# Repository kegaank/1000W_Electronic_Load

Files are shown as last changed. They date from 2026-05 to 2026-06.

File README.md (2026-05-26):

# 1000W 可编程直流电子负载

> **项目代号**: EL-1000  |  **12维度闭环管理 v3.0**  |  **人机协作模式**

---

## 项目速览

| 项 | 值 |
|---|---|
| 产品定位 | ITECH级精度 + 美尔诺级定价 + 现代化软件体验 |
| 目标零售价 | ¥3,999-5,999（约$550-830） |
| 核心规格 | 1000W连续 / 0-150V / 0-60A / 0.1%精度 / Wi-Fi+BLE+USB |
| 团队 | 创始人（执行合伙人）+ AI数字化研发团队 |
| 开发周期 | 24周（6个月）至首次发布 |

---

## 目录结构

```
1000W_Electronic_Load/
├── README.md                 ← 本文件
├── 01_市场调研/              ← 竞品分析、用户画像、市场报告
├── 02_产品定义/              ← PRD、SRD、ID Brief
├── 03_系统设计/              ← 系统架构图、功率拓扑、热设计
├── 04_外观结构/              ← ID设计需求、3D模型、结构图纸
├── 05_硬件研发/              ← 原理图、PCB、BOM
├── 06_软件研发/              ← 固件、Web UI、App、云端
├── 07_测试验证/              ← 测试计划、校准流程、测试报告
├── 08_供应链/                ← 供应商列表、比价表、采购订单
├── 09_推广运营/              ← 博客、视频脚本、众筹文案
├── 10_销售渠道/              ← 电商文案、FAQ、产品说明书
├── 11_客户成功/              ← 用户手册、NPS问卷、反馈汇总
├── 12_项目管理/              ← 排期表、评审材料、风险追踪
├── _archive/                 ← 历史版本归档
├── _templates/               ← 文档模板
└── _meeting_notes/           ← 评审会议纪要
```

---

## 12维度 → 角色分工

| 角色 | 负责维度 | 成员 |
|---|---|---|
| A: 产品/市场 | 01, 02, 09, 10, 11 | 创始人 + AI辅助 |
| B: 系统/硬件 | 03, 04, 05, 07, 08 | 创始人 + AI辅助 |
| C: 软件 | 06 | AI主力 + 创始人测试 |
| D: 项目管理 | 12 | AI主力 + 创始人审核 |

---

## 阶段 & 里程碑

| 阶段 | 时间 | 关键节点 |
|---|---|---|
| 调研&定义 | W1-W6 | W6: SDR系统设计评审 |
| 设计&原型 | W7-W14 | W14: 原型机验收 |
| 验证&量产 | W15-W20 | W20: 发布就绪评审 |
| 发布&运营 | W21+ | 众筹/电商正式上线 |

---

## 协作流程

```
会话开始 → AI产出本周交付物 → 创始人执行物理任务 → 反馈结果 → 状态更新 → 下一周
```

---

## Git 仓库

> 初始化后填入仓库地址

---

*Created: 2026-05-26  |  Version: 1.0  |  密级: 内部*

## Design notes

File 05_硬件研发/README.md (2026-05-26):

# 05 硬件研发

## 子目录
```
05_硬件研发/
├── README.md
├── 原理图/
├── PCB/
├── BOM/
├── 调试日志/
└── 版本记录/
```

## 关键交付物

| 文档 | 状态 | 负责人 |
|---|---|---|
| 原理图（KiCad） | ⏳ 待开始 | AI |
| PCB Layout 指南 | ⏳ | AI |
| BOM 物料清单 V1.0 | ⏳ | AI |
| PCB Gerber 文件 | ⏳ | 用户 |
| 焊接 & 调试日志 | ⏳ | 用户 |
| 硬件版本迭代记录 | ⏳ | AI |

## 对应周次
W8-W14（V1.1持续迭代）

## 联动维度
- ← 03 系统设计
- ← 04 外观结构（PCB外形/限高）
- → 06 软件研发（联调）
- → 07 测试验证

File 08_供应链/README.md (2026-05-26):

# 08 供应链与生产制造

## 子目录
```
08_供应链/
├── README.md
├── PCB_供应商/
├── 元器件/
├── 结构件/
├── 组装/
├── 比价表/
└── 采购订单/
```

## 关键交付物

| 文档 | 状态 | 负责人 |
|---|---|---|
| 量产 BOM + 供应商比价表 | ⏳ | AI |
| 供应链跟踪表 | ⏳ | AI |
| 元器件采购订单 | ⏳ | 用户 |
| 结构件（模具/钣金）订单 | ⏳ | 用户 |
| 首批50台生产指导文档 | ⏳ | AI |

## 对应周次
W16-W20（持续管理）

## 联动维度
- ← 04 外观结构（模具需求）
- ← 05 硬件研发（BOM清单）
- ← 07 测试验证（验证通过后启动）
- → 10 销售渠道（量产成品）

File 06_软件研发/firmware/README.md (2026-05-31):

# EL-1000 Firmware — 1000W Programmable DC Electronic Load

## Overview

Dual-MCU architecture for a 1000W programmable DC electronic load.

| MCU | Role | Key Features |
|-----|---|---|
| **C2000 F28E12x** | Real-time control | PID @860Hz, protection @1ms, HRPWM @25kHz |
| **ESP32-S3** | Communication & UI | Wi-Fi 6 + BLE 5.0, WebSocket/REST API, 4.3" IPS LCD |

## Directory Layout

```
firmware/
├── README.md            ← This file
├── c2000/               ← C2000 F28E12x firmware (C/FreeRTOS)
│   ├── CMakeLists.txt
│   ├── main.c
│   ├── FreeRTOSConfig.h
│   ├── tasks/           ← FreeRTOS task implementations
│   ├── drivers/         ← Peripheral driver layer
│   └── control/         ← Control loop logic (PID, modes)
├── esp32/               ← ESP32-S3 firmware (ESP-IDF)
│   ├── CMakeLists.txt
│   ├── main/            ← Application code
│   └── components/      ← LVGL, protocol handlers
├── common/              ← Shared types & protocol definitions
└── docs/                ← Architecture documentation
```

## Build Instructions

### C2000
1. Open CCS Theia, import `firmware/` as a CCS project.
2. Select build target: `F28E12x`.
3. Build and flash via XDS110 debug probe.

### ESP32
1. Source ESP-IDF environment:
   ```
   . $HOME/esp/esp-idf/export.sh
   ```
2. Build:
   ```
   cd firmware/esp32
   idf.py build
   ```
3. Flash:
   ```
   idf.py -p /dev/ttyUSB0 flash monitor
   ```

## Inter-MCU Communication

UART (SCI-A on C2000 ↔ UART0 on ESP32) using a custom binary protocol defined in `common/protocol.h`.  
Baud rate: 921600. Packet format: start byte + length + command + payload + CRC.

## Real-Time Constraints

| Loop | Frequency | Deadline | MCU |
|---|---|---|-----|
| PID current control | 860 Hz | 1.16 ms | C2000 |
| Protection monitor | 1 kHz | 1.00 ms | C2000 |
| HRPWM update | 25 kHz | 40 µs | C2000 (ISR) |
| UART comms | 100 Hz | 10 ms | Both |
| Display refresh | 30 Hz | 33 ms | ESP32 |
| WebSocket push | 10 Hz | 100 ms | ESP32 |

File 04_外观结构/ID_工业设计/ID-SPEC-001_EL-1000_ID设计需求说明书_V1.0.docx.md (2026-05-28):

# ID-SPEC-001 EL-1000 电子负载 ID 设计需求说明书 v1.0

> 本文件为 1000W 可编程直流电子负载（项目代号 EL-1000）的工业设计需求文档，
> 供后续 3D 建模（Fusion 360 / SolidWorks）及手板制作使用。
> 对应阶段：04_外观结构/ID_工业设计
> 状态：定稿 | 日期：2026-05-28

---

## 1. 设计风格定位

### 1.1 品牌参考
- **参考品牌**：ITECH（艾德克斯）8500 系列电子负载
- **风格关键词**：专业仪器、分区布局、深色沉稳、精密感

### 1.2 竞品差异目标
- 不像入门级单片机壳
- 不像 DIY 实验设备
- 定位中型台式精密仪器

---

## 2. CMF 规范

### 2.1 颜色

| 应用区域 | 色号 | 色值 | 备注 |
|---|---|---|---|
| 机身主色 | RAL 7021 | 深灰黑 (#2b2b2b) | 哑光表面 |
| 前面板 | RAL 7021 | 深灰黑渐变 | 顶部略浅，底部略深 |
| 装饰条/品牌色 | — | 青绿 #00a884 | 顶部横贯条 + 品牌元素 |
| 旋钮/按键 | — | 深灰 (#333-#444) | 哑光，浅色字符 |
| 正极端子 | — | 红色 | 四线接入 |
| 负极端子 | — | 蓝色 | 四线接入 |
| 屏幕底色 | — | 深蓝黑 (#0a1628) | IPS 暗色主题 |
| 前面板丝印 | — | 浅灰 (#ddd-#bbb) | 哑光 |

### 2.2 材质
| 部件 | 材质 | 表面处理 |
|---|---|---|
| 机身壳体 | 冷轧钢板 SPCC，厚 1.2mm~1.5mm | 静电粉末喷涂 RAL 7021 哑光 |
| 前面板 | 铝合金 5052 或 6063 | 喷砂 + 阳极氧化深灰，局部拉丝 |
| 后盖 | 冷轧钢板，厚 1.0mm | 静电粉末喷涂 |
| 散热器 | 铝型材 AA6063 | 本色喷砂 + 阳极氧化 |
| 旋钮 | 铝合金 + 硅胶防滑圈 | 阳极氧化深灰 |
| 按键 | POM 或 ABS | 哑光注塑 + 激光雕刻字符 |
| 脚垫 | 硅橡胶 | 黑色，防滑 |

### 2.3 表面处理
- 前面板不做拉丝（ITECH 风格为细磨砂质感）
- 所有棱边倒角 R1~R2
- 接缝均匀 ≤0.3mm
- 丝印字符：白/浅灰，耐磨，键帽不掉字

---

## 3. 整机尺寸

### 3.1 外形尺寸
| 项目 | 数值 |
|---|---|
| 宽度 | 310 mm |
| 深度 | 370 mm（含前面板旋钮和后面板端子凸出） |
| 高度 | 120 mm（含脚垫约 125mm） |
| 重量估算 | 约 4.5~5.5 kg |
| 脚垫高度 | 5 mm |

### 3.2 散热布局
- 顶部开散热格栅（整面通风，压型或冲网）
- 左右侧板下方开进风口
- 内部风扇：后侧 80mm×80mm ×2 轴向风扇向后排风
- 散热器脊柱居中，8×M90N20 背靠背贴装（与方案A一致）

---

## 4. 前面板布局（核心设计）

### 4.1 分区总览（从上到下）

```
┌─────────────────────────────────────────────────────┐
│                  4.3" IPS 屏幕                      │ ← 上区：全宽屏幕显示
│                    (全宽)                 [编码器]  │       右上角编码器
├────────────┬─────────┬──────────────────────────────┤
│ [电源开关] │ CV CC CW│   [On/Off]  [Recall/Save]   │ ← 中区：模式键+操作键
│  (旋转)    │ CR LED  │   [Menu]    [Esc]           │
│            │ BAT Dyn │                              │
├────────────┴─────────┴──────────────────────────────┤
│   [1] [2] [3]    [↑]    [V-set]   [A-set]          │ ← 下区左：数字键盘+导航
│   [4] [5] [6]  [←][↓][→]  [Enter]  [Output On/Off] │        + 青绿开机键
│   [7] [8] [9]                                      │
│   [0] [.][-/E]     [Local]                         │
├─────────────────────────────────────────────────────┤
│         ─── ⚫红  ⚫蓝 ─── 输入端子                  │ ← 下区右：四线输入端子
│               +      -                              │        (偏右布置)
└─────────────────────────────────────────────────────┘
```

### 4.2 详细分区坐标（3D 建模参考，以前面板左上角为原点）

| 区域 | 位置 (X, Y) | 尺寸 (W×H) | 说明 |
|---|---|---|---|
| 屏幕区 | (15, 15) | 280 × 72 | 4.3" IPS，暗色主题 UI |
| 编码器 | (272, 20) | Ø18 | 屏幕右上角，金属防滑旋钮 |
| 电源开关 | (20, 108) | Ø22 | 左侧，旋转式 ON/OFF |
| 模式键 4×2 | (52, 102) | 80 × 32 | CV/CC/CW/CR（上排）+ LED/BAT/Dyn（下排） |
| 操作键 2×2 | (142, 102) | 60 × 32 | On/Off, Recall/Save, Menu, Esc |
| 数字键盘 | (15, 150) | 70 × 50 | 10 键 + 小数点 + 负号 |
| 导航键 | (95, 160) | 30 × 30 | 十字方向 + Enter |
| 功能键 | (95, 135) | 60 × 18 | V-set, A-set, Output On/Off |
| 输入端子 | (185, 148) | — | 四线 Kelvin 接入，红+/蓝- |
| 品牌标识 | 屏幕左下方或右下方 | — | "EL-1000" 丝印，青绿 #00a884 |

### 4.3 关键交互元件规格

| 元件 | 型号建议 | 数量 | 备注 |
|---|---|---|---|
| 屏幕 | 4.3" IPS，480×272/800×480，50pin | 1 | 建议带有 RGB 接口或 SPI |
| 编码器 | EC11/EC12 系列，20脉冲/转 | 1 | 带按键功能 |
| 电源开关 | 旋转式带灯，2位 SPDT | 1 | 红色 LED 指示 |
| 薄膜按键 | 4×4 矩阵 + 单独功能键 | ~20 | 背光可选 |
| On/Off 输出键 | 大型带灯按键，青绿色 | 1 | 仪器操作焦点 |
| 接线端子 | 四线 Kelvin，30A 额定 | 2 | 红色(正) + 蓝色(负) |
| 脚垫 | 硅胶椭圆垫 20×10×5 | 4 | 四角布置 |

---

## 5. 后面板布局

```
┌─────────────────────────────────────────────────────┐
│                                                     │
│          ╔══════════════════╗                        │
│          ║   散热风扇 80×80  ║                        │
│          ║   (×2 并排)      ║                        │
│          ╚══════════════════╝                        │
│                                                     │
│  [IEC AC输入] [电源开关] [USB-B] [SMA触发] [PMBus]   │
│                                                     │
│  ┌──────────────────────────────────────────────────┐│
│  │  型号标签 / 序列号 / 认证标识                    ││
│  └──────────────────────────────────────────────────┘│
└─────────────────────────────────────────────────────┘
```

**后盖接口清单：**

| 接口 | 类型 | 位置 | 备注 |
|---|---|---|---|
| 电源输入 | IEC C14 带保险丝座 | 左侧 | 90~264VAC 通用 |
| 电源开关 | 船型开关，带灯 | 电源入口旁 | 与前面电源开关串联？需确认 |
| USB | USB-B (设备) 或 USB-C | 左侧接口区 | 用于 PC 通信/固件升级 |
| SMA | SMA 母座 | 左侧接口区 | 外部触发输入 |
| PMBus | RJ45 或 4P 端子 | 左侧接口区 | SMBus/I²C 数字接口 |
| 风扇 | 80×80×25mm ×2 | 上部并排 | PWM 温控调速 |

---

## 6. 内部结构约束（继承方案A）

### 6.1 热管理
- **散热器**：铝挤型材，居中布置，导热面朝向功率管
- **功率管**：8×M90N20，背靠背对称安装于散热器两侧
- **风扇**：后侧 80×80×25mm ×2，抽风式，PWM 温控
- **风流路径**：侧板进风 → 散热器鳍片 → 后侧风扇排出
- **发热源隔离**：功率区与控制系统（C2000主板、ESP32）保持间距

### 6.2 PCB 安装
- 功率主板：紧贴散热器安装，用导热硅脂+绝缘垫片
- C2000 DSP 控制板：功率板上方或独立支架安装
- ESP32-S3 通信板：远离功率区域
- 反激辅助电源：独立小板，靠近 IEC 输入

### 6.3 结构件
- 脊柱式钣金骨架（2mm SPCC 折弯）作为整机结构支撑
- 散热器同时也是结构件，与骨架刚性连接
- 前面板：铝合金 CNC 或压铸，通过 M3 螺钉固定于骨架

---

## 7. 设计交付物要求（供设计师参考）

当进入 3D 建模阶段，需输出：

| 交付物 | 格式 | 说明 |
|---|---|---|
| 整机 3D 模型 | STEP (.stp/.step) | 带全部装配零件 |
| 渲染图 | PNG 4K | 45°轴测 × 前正视图 × 后面板 |
| 爆炸图 | PNG/PDF | 标注全部零件 |
| 工程图 | PDF/DWG | 带尺寸标注，供钣金/加工使用 |
| PCB 限位图 | STEP/PDF | 关键安装孔位/高度限制 |
| BOM（结构件） | XLSX | 含材质/表面处理/供应商信息 |
| CMF 样卡 | PDF | 色号/纹理/表面处理实物对照 |

---

## 8. 修订记录

| 版本 | 日期 | 变更内容 | 作者 |
|---|---|---|---|
| v1.0 | 2026-05-28 | 初版，依据 ITECH 风格方案B-v3 定稿 | AI Hermes |

---

*本文件为 ID 输入端条件文件，实际 3D 建模时需结合 PCB 尺寸、散热仿真结果、钣金折弯工艺等综合修正。*

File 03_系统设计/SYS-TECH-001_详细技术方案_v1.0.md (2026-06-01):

# SYS-TECH-001 EL-1000 详细技术方案 v1.0

> **项目**: EL-1000 1000W 可编程直流电子负载
> **版本**: v1.0
> **日期**: 2026-06-01
> **状态**: 初稿 — 整合全部子系统设计

---

## 目录

1. [产品概述](#1-产品概述)
2. [系统架构](#2-系统架构)
3. [功率拓扑](#3-功率拓扑)
4. [控制架构](#4-控制架构)
5. [电源树](#5-电源树)
6. [安全架构](#6-安全架构)
7. [热设计](#7-热设计)
8. [通信协议](#8-通信协议)
9. [控制算法](#9-控制算法)
10. [固件架构](#10-固件架构)
11. [外观结构](#11-外观结构)
12. [整机BOM](#12-整机bom)
13. [关键接口定义](#13-关键接口定义)
14. [测试验证方案](#14-测试验证方案)

---

## 1. 产品概述

### 1.1 产品定位

EL-1000 是一款 1000W 可编程直流电子负载，面向电源研发、电池测试、老化筛选等场景。对标 ITECH 8500 系列，采用 ITECH 风格外观，定位中端市场。

### 1.2 关键规格 (SRD v1.3)

| 参数 | 值 | 备注 |
|---|-----|---|
| 额定功率 | 1000 W | 峰值 1200 W (<30s) |
| 额定电压 | 150 V | |
| 额定电流 | 60 A | |
| 最小工作电压 | 1.5 V @ 60A | |
| 工作模式 | CC / CV / CR / CW | CR/CW 固件规划中 |
| 分辨率 | 0.01 A / 0.01 V | HRPWM 15.2 bit |
| 精度 | ±0.1% FS (V) / ±0.2% FS (A) | 校准后 |
| 纹波 | <10 mVrms | |
| 通信 | USB / Wi-Fi / UART / CAN | |
| 显示 | 4.3" IPS 彩屏 | ESP32 LVGL |
| 外形 | W310×D370×H120mm | ITECH 风格 |
| 整机 BOM | ¥1,354 | 小批量 50-200 台 |
| 目标零售 | ¥3,999–5,999 | |

### 1.3 工作模式说明

| 模式 | 控制策略 | 说明 |
|---|---|---|
| **CC** (Constant Current) | 电流 PID → Duty | 直接控制负载电流，最常用模式 |
| **CV** (Constant Voltage) | 电压 PID → 电流 PID → Duty | 级联控制，稳压在输入端 |
| **CR** (Constant Resistance) | 电阻 PID → 电流 PID → Duty | 等效固定电阻负载（规划中） |
| **CW** (Constant Power) | 功率 PID → 电流 PID → Duty | 恒定功率吸收（规划中） |

---

## 2. 系统架构

### 2.1 整机框图

```
                          ┌────────────────────────────────────┐
                          │          EL-1000 整机架构            │
                          │                                      │
   ┌──────────┐          │  ┌──────────┐     ┌──────────────┐  │
   │   DUT    │──────────┼─►│  功率级   │◄────│   控制电路    │  │
   │ (被测件) │          │  │12×M90N20 │     │ C2000 + ESP32│  │
   └──────────┘          │  │  RS6332  │     │  ISO隔离     │  │
         │               │  │ D882/B772│     │  SGM71622R2  │  │
         │   ┌──────────┐│  └────┬─────┘     └──────┬───────┘  │
         │   │ 电源树    ││       │                   │          │
         └───┤ AC→48V→  ││       │   ┌───────────┐   │          │
             │ 12V/5V/  ││       └───│ 散热系统   │   │          │
             │ 3.3V/-15V││           │ 铝挤+双120 │   │          │
             └──────────┘│           └───────────┘   │          │
                         └────────────────────────────┘          │
                                       │                          │
                              ┌────────┴────────┐                │
                              │  前后面板 I/O    │                │
                              │ USB/WiFi/编码器  │                │
                              │ 急停/接线柱/FAN  │                │
                              └─────────────────┘                │
```

### 2.2 信号流

**控制路径**（C2000 内部，860 Hz）:
```
Setpoint → Mode Select → PID Compute → HRPWM → RC Filter → D882/B772 → MOSFET Gate
                              ↑                                    │
                         ADC Read ◄──── RS6332 Sense ◄──── Source Resistor
```

**数据路径**（C2000 → ESP32，921600 baud UART）:
```
C2000 housekeeping → ring buffer → comm task → UART → ESP32 uart_rx
                                                          │
                                                    ┌─────┴─────┐
                                                    │ LVGL UI   │
                                                    │ WebSocket │
                                                    │ REST API  │
                                                    └───────────┘
```

### 2.3 子系统划分

| 子系统 | 核心 IC | 功能 | PCB 分配 |
|---|---|---|---|
| 功率级 | M90N20 ×12, RS6332, D882/B772 | MOSFET 阵列 + 电流采样 + 栅极驱动 | 功率主板 |
| 控制电路 | C2000 F28E12x, ESP32-S3 | PWM 生成 + PID 运算 + UI 通信 | 控制板 |
| 电源树 | UCC28C45, Buck LDO 阵列 | AC→DC 供电 | 电源子板 |
| 安全防护 | CMPSS, 继电器, 熔丝 | 5 道防护 + 3 重切断 | 跨板 |
| 散热 | 铝挤 + 双 120mm PWM 风扇 | 热管理 | 机箱固定 |

---

## 3. 功率拓扑

### 3.1 MOSFET 阵列

**选型**: M90N20 (200V/90A TO-247)

| 参数 | 值 | 说明 |
|---|-----|---|
| Vds(max) | 200 V | 150V 降额 75% |
| Id(max) | 90 A | 单管 |
| Rds(on) | 22 mΩ | Vgs=10V |
| gm | 20 S (typ@8A) | |
| Pd(max) | 310 W | Tc=25°C |
| 数量 | 12 管 | 原型 10 管可用 |
| 总 Id | 1080 A | 远超 60A 需求 |
| 并联均流 | 源极 0.05Ω 电阻 | 12 × 0.05Ω 并联 = 0.004167Ω |
| 绝缘 | AlN 氮化铝垫片 | 热阻 0.4°C/W |

**并联结构**:
```
               ┌─── M90N20_1 ── 0.05Ω R_sense_1 ──  GND
               │
   Gate_drive ──┼─── M90N20_2 ── 0.05Ω R_sense_2 ──  GND
    (D882/B772) │         ...    (共 12 路)
               └─── M90N20_12 ─ 0.05Ω R_sense_12 ── GND
               
               DUT+ ────────────────────────────── MOSFET Drain
               所有 Source 在 GND 侧通过 RS6332 差分采样
```

**均流分析**:
- 源极电阻 0.05Ω 提供负反馈：电流大的管 Vgs 自动降低
- 12 管并联等效 R_sense = 0.004167Ω
- 满载 60A 时源极电阻压降: 60 × 0.004167 = 0.25V
- ADC 采样电压 (RS6332 增益 10): 0.25 × 10 = 2.5V (在 3.3V ADC 范围内)

### 3.2 栅极驱动

**方案**: D882(NPN) + B772(PNP) 推挽射极跟随器

| 参数 | 值 | 说明 |
|---|-----|---|
| 拓扑 | 互补推挽 | 快速充放电 Cgs |
| 驱动电压 | ~3.0 V (0.95×3.3V) | RC 滤波后 |
| 峰值电流 | ~1 A | D882/B772 能力 |
| 关断速度 | <1 µs | N7002N 下拉加速 |
| 数量 | 2 组推挽 (驱动 12 管) | 每组驱动 6 管 |

**驱动路径**:
```
C2000 HRPWM → RC LPF (10k+1µF, fc=15.9Hz) → Vdac (0~3.135V)
    → LM358 缓冲 → D882/B772 推挽 → 12× M90N20 Gate
                                          │
                                    N7002N 下拉电阻 10kΩ
```

**HRPWM→DAC 转换**:
```
PWM: 25 kHz, 占空比 D = 0~0.95
Vdac = D × 3.3V = 0 ~ 3.135V (经 RC 滤波)
等效分辨率: log2(25kHz / 15.9Hz × 0.95) ≈ 15.2 bit

替代方案: GP8101 (PWM→模拟, ¥2.5, SOP-8)
         可免去 RC 滤波，直接出 0~5V 模拟电压
```

### 3.3 电流检测

| 元件 | 规格 | 说明 |
|---|---|---|
| 检流电阻 | MCSF2512DR050Q9 (0.05Ω, 3W, 2512) | 12 颗并联 |
| 差分放大器 | RS6332 (替代 LM358, Vos 0.8mV) | 增益 10 倍 |
| 增益 | 0.04167 V/A (等效) | 60A → 2.5V ADC 输入 |

**精度预算**:
```
检流电阻精度: ±1% (MCSF2512)
RS6332 Vos: 0.8mV (max)
60A 时信号: 2.5V
Vos 误差: 0.8mV / 2.5V = 0.032%
校准后可达成 ±0.2% FS
```

### 3.4 电压检测

| 元件 | 规格 | 说明 |
|---|---|---|
| 分压比 | 1:13.2 | 150V → 11.36V → 3.3V ADC |
| 分压电阻 | 高精度 ±0.1% | 温度系数 25ppm |
| ADC 输入 | 0~3.3V | C2000 内置 ADC (12bit) |
| 等效分辨率 | 150V / 4096 ≈ 36.6mV/LSB | 软件过采样提升 |

---

## 4. 控制架构

### 4.1 双 MCU 方案

| MCU | 型号 | 角色 | 关键外设 |
|-----|---|---|---|
| 主控 | C2000 F28E12x | 实时控制 | HRPWM (150ps), ADC (12b, 13ch), CMPSS, SCI |
| 通信 | ESP32-S3 | UI/网络 | Wi-Fi/BLE, SPI (LCD), UART, LVGL |

**分工**:
```
C2000 (实时域):    ESP32 (非实时域):
┌──────────────┐   ┌──────────────────────┐
│ PID @860Hz   │   │ LVGL UI @30Hz        │
│ HRPWM        │   │ WebSocket @10Hz      │
│ ADC @860Hz   │   │ REST API             │
│ Protection   │   │ Wi-Fi 管理           │
│ 25kHz PWM    │   │ UART 协议处理        │
└──────┬───────┘   └──────────┬───────────┘
       │                      │
       └──── UART 921600 ─────┘
```

### 4.2 C2000 F28E12x 资源分配

| 外设 | 用途 | 占用 |
|---|---|---|
| ePWM1 | HRPWM 主输出 (25 kHz, 150ps) | 1 通道 |
| ePWM2-3 | 备用/风扇 PWM | 2 通道 |
| ADC A/B | 13 通道交错采样 | 全部 |
| CMPSS 1-3 | HW OVP/OCP/UVLO | 3 组 |
| SCI-A | UART ↔ ESP32 (921600) | 1 路 |
| I2C-A | 板载 EEPROM/温度传感器 | 1 路 |
| GPIO | 继电器/故障指示/急停 | 8 个 |

### 4.3 HRPWM 配置

| 参数 | 值 | 说明 |
|---|-----|---|
| 频率 | 25 kHz | Tperiod = 40 µs |
| 时基 | TBPRD = 2000 (SYSCLK=100MHz) | |
| MEP 分辨率 | ~150 ps | 等效 16.7 bit |
| 死区 | 200 ns | 同步整流预留 |
| 占空比范围 | 0~95% | TBPRD × 0.95 |
| Trip Zone | TZ1/CMPSS1, TZ2/CMPSS2, TZ3/SW | 硬件强制 Hi-Z |

### 4.4 隔离方案

| 隔离边界 | 器件 | 隔离等级 | 信号 |
|---|---|---|---|
| 功率→控制 | ISO7741 | 5kV | 故障/状态信号 |
| USB 隔离 | ADuM3160 | 2.5kV | USB↔C2000 |
| CAN 隔离 | ADuM1201 + SN65HVD230 | 2.5kV | CAN 总线 |
| 电源隔离 | B0505S × 2, B1515S | 3kV | 隔离供电 |

---

## 5. 电源树

### 5.1 整体架构

```
AC 220V ──► EMI ──► 整流桥 ──► 310V DC Bus
                                    │
                              ┌─────┴─────┐
                              │ UCC28C45  │  (子板, 65kHz CCM)
                              │ 反激变换器 │
                              └─────┬─────┘
                                    │
                          ┌─────────┼──────────┐
                          │         │          │
                        +48V      +15V      -15V
                     (150W)     (辅助运放)  (电荷泵)
                          │
              ┌───────────┼───────────┐
              │           │           │
           Buck1       Buck2       Buck3
          +12V(3A)    +5V(2A)    +3.3V(2A)
              │           │           │
              │       ┌───┴───┐   ┌──┴───┐
              │      LDO     LDO  LDO   LDO
              │     3.3V    3.3V  1.8V  1.2V
              │     (ESP32) (C2000)
              │
          风扇 / 继电器
```

### 5.2 电压轨清单

| 电压轨 | 来源 | 用途 | 电流 | 纹波要求 |
|---|---|---|---|---|
| +48V | 反激主输出 | 预留扩展 | 3A | <100mV |
| +15V | 反激绕组 | RS6332/D882 供电 | 0.5A | <50mV |
| -15V | 电荷泵 (ICL7660) | 可选负压 | 0.1A | <50mV |
| +12V | Buck1 (LM2596) | 风扇/继电器 | 3A | <100mV |
| +5V | Buck2 (MP2307) | USB/逻辑 | 2A | <30mV |
| +3.3V | Buck3 → LDO | ESP32/C2000 | 2A | <20mV |
| +1.8V | LDO (AMS1117) | C2000 内核 | 0.3A | <10mV |
| +1.2V | LDO | C2000 PLL | 0.2A | <10mV |

### 5.3 反激变换器 (UCC28C45)

| 参数 | 值 |
|---|-----|
| 拓扑 | CCM 反激 |
| 频率 | 65 kHz |
| 输入 | 310 VDC |
| 输出 | 48V/150W + 辅助绕组 |
| 控制 IC | UCC28C45 (独立, 非 HRPWM) |
| 反馈 | TL431 + 光耦 |
| 保护 | OCP (CS 电阻), OVP (TL431 钳位) |

> **设计理由**: 反激子板独立于主控板，不依赖 C2000 HRPWM。
> 释放 HRPWM 全部用于 MOSFET 栅极驱动控制。

---

## 6. 安全架构

### 6.1 5 道防护体系

| 层级 | 防护 | 时间 | 器件 | 触发条件 |
|---|---|---|---|---|
| **L1** | 硬件 CMPSS | <1 µs | CMPSS1/2 (C2000) | V>150V 或 I>110A |
| **L2** | 硬件 PWM Trip | <100 ns | TZ 强制 Hi-Z | CMPSS 触发 |
| **L3** | 栅极下拉 | <15 µs | N7002N | GPIO 故障信号 |
| **L4** | 继电器断开 | 5-10 ms | 功率继电器 × 2 | 软件保护触发 |
| **L5** | 熔丝终级 | — | 125A 快断熔丝 | 前 4 级均失效 |

### 6.2 保护阈值

| 保护项 | 软件阈值 | 硬件阈值 | 动作 | 恢复 |
|---|---|---|---|---|
| OVP | 150V | 155V (CMPSS1) | PWM Trip + 继电器 | 手动清除 |
| OCP | 110A | 115A (CMPSS2) | PWM Trip + 继电器 | 手动清除 |
| OPP | 1050W | — | 功率折返 | 自动 |
| OTP 降额 | 75°C | — | 功率线性降额 | 自动 |
| OTP 关断 | 90°C | — | PWM 关断 | 手动清除 |
| UVLO (PSU) | 10.8V | — | 系统安全关断 | 自动 |
| 通信超时 | 500ms | — | 保持 + 警告 | 自动 |

### 6.3 故障处理流程

```
故障触发
    │
    ├── L1/L2 (硬件): 直接 Hi-Z, <1µs
    │   └── 记录故障标志到 EEPROM
    │
    ├── L3 (软件保护): PID 任务检测
    │   ├── OVP/OCP: 立即关断 PWM
    │   ├── OTP: 75°C 折返 → 90°C 关断
    │   └── OPP: 功率限制
    │
    └── 恢复: 需手动清除 (CMD_CLEAR_FAULT)
          └── 急停也可物理复位
```

---

## 7. 热设计

### 7.1 散热方案

| 组件 | 散热方式 | 规格 |
|---|---|---|
| MOSFET × 12 | 铝挤压散热器 | 350×150×50mm |
| AlN 绝缘垫 | 导热垫片 | TO-247, θjc=0.4°C/W |
| 散热风扇 | PWM 双 120mm | 12V, 可调速 |
| 热管理策略 | PID 控温 | 目标 65°C 以下 |

### 7.2 热阻链

```
Tj (MOSFET 结温)
    │  θjc = 0.3°C/W (M90N20)
Tcase
    │  θcs = 0.4°C/W (AlN 垫片)
Theatsink
    │  θsa = 0.06°C/W (350×150×50mm 铝挤 + 2.5m/s 风冷)
Tambient (40°C)
```

**1000W 满载温升**:
```
单管功耗: P_total / 12 = 83.3W (假设均匀)
Tj = 40 + 83.3 × (0.3 + 0.4 + 0.06) = 40 + 83.3 × 0.76
Tj = 40 + 63.3 = 103.3°C ✅ (M90N20 Tjmax=175°C, 降额 59%)
```

### 7.3 风扇策略

| 温度区间 | 风扇转速 | 说明 |
|---|---|---|
| <45°C | 0% (停转) | 静音模式 |
| 45-55°C | 20-40% | 低速散热 |
| 55-70°C | 40-80% | 中速 |
| 70-85°C | 80-100% | 全速 |
| >85°C | 100% + 功率折返 | 过热保护 |

---

## 8. 通信协议

### 8.1 协议层级

```
            ┌─────────────────────────┐
            │     应用层协议           │
            │  SCPI-like 文本命令     │
            └───────────┬─────────────┘
                        │
        ┌───────────────┼───────────────┐
        │               │               │
   ┌────┴────┐   ┌─────┴─────┐   ┌────┴────┐
   │  USB    │   │  Wi-Fi    │   │  CAN    │
   │ (CDC)   │   │(WebSocket)│   │(2.0B)   │
   └────┬────┘   └─────┬─────┘   └────┬────┘
        │              │              │
   ┌────┴──────────────┴──────────────┴────┐
   │          UART 921600 baud             │
   │          Byte frame protocol          │
   └───────────────────────────────────────┘
```

### 8.2 UART 帧格式 (C2000 ↔ ESP32)

```
Sync0  Sync1  Length  Cmd    Payload    CRC16
 0xAA   0x55    1B     1B    0-255B     2B
```

| 命令 | 编码 | 方向 | 说明 |
|---|---|---|---|
| CMD_SET_MODE | 0x01 | ESP→C2000 | CC/CV/CR/CW |
| CMD_SET_CURRENT | 0x02 | ESP→C2000 | 设置电流 (mA) |
| CMD_SET_VOLTAGE | 0x03 | ESP→C2000 | 设置电压 (mV) |
| CMD_SET_OUTPUT | 0x04 | ESP→C2000 | ON/OFF |
| CMD_GET_TELEM | 0x10 | ESP→C2000 | 请求遥测 |
| CMD_TELEM_DATA | 0x11 | C2000→ESP | 遥测数据 |
| CMD_CLEAR_FAULT | 0x20 | ESP→C2000 | 清除故障 |
| CMD_SET_CAL | 0x30 | ESP→C2000 | 校准命令 |
| CMD_GET_STATUS | 0x40 | ESP→C2000 | 状态查询 |

**遥测数据包 (CMD_TELEM_DATA, 28 字节)**:
```
Offset  Size  Field           Unit
  0      4    V_load          mV
  4      4    I_load          mA
  8      4    P_load          mW
  12     4    V_fan_pwm       %
  16     4    Temp_1          °C×100
  20     4    Temp_2          °C×100
  24     4    Status flags    bitmask
```

### 8.3 SCPI 命令集 (USB/Wi-Fi 用户接口)

| 命令 | 参数 | 示例 |
|---|---|---|
| `:INPut:STATe` | ON/OFF | `:INPut:STATe ON` |
| `:SOURce:FUNCtion` | CC/CV/CR/CW | `:SOURce:FUNC CC` |
| `:SOURce:CURRent` | 0-60.00 | `:SOURce:CURR 5.00` |
| `:SOURce:VOLTage` | 0-150.00 | `:SOURce:VOLT 12.00` |
| `:MEASure:CURRent?` | — | 返回电流值 |
| `:MEASure:VOLTage?` | — | 返回电压值 |
| `:SYSTem:ERRor?` | — | 返回错误代码 |
| `:CALibrate:STATe` | ON/OFF | 进入/退出校准 |

> WebSocket 接口使用 JSON 格式传输相同数据：
> ```json
> {"cmd":"set_current","params":{"value":5.00,"unit":"A"}}
> ```

---

## 9. 控制算法

### 9.1 算法架构

**级联控制**:
```
Setpoint ──► Mode Select ──► Outer Loop PID ──I_demand──► Inner Current PID ──Duty──► HRPWM
                                                           ↑
                                                    Current Feedback (860Hz)
```

### 9.2 PID 实现

**并联式 PI (离散)**:
```
error[n]       = setpoint - measurement[n]
p_term[n]      = Kp × error[n]
i_term[n]      = i_term[n-1] + Ki × error[n] × dt
output[n]      = p_term + i_term
output[n]      = clamp(output, min, max)
```

**抗饱和**:
```
if output >= max AND error > 0:  i_term[n] = i_term[n-1]  (冻结)
if output <= min AND error < 0:  i_term[n] = i_term[n-1]  (冻结)
else:                            i_term[n] = i_term[n-1] + Ki × error × dt
i_term[n] = clamp(i_term[n], ±max_integral)
```

### 9.3 PI 参数 (初始值)

| 环路 | Kp | Ki (离散) | Kd | 输出范围 | 说明 |
|---|----|---|-----|---|---|
| 电流环 (内环) | 0.5 | 10.0 | 0.001 | 0~0.95 duty | Ts=1.163ms |
| 电压环 (外环) | 0.2 | 2.0 | 0.0 | 0~110A I_demand | 带宽<<电流环 |

**仿真验证结论** (pid_sim.py):
```
电流环:
- 相位裕度: 109° (稳定)
- 闭环带宽: 112 Hz
- max_integral 需 ≥ 0.88 (30A 稳态 duty ≈ 0.88)
- 最终取 max_integral = 0.95
```

### 9.4 采样时序

```
PID 周期 T = 1/860 ≈ 1.163 ms

┌─────────┐  ┌─────────┐  ┌─────────┐  ┌─────────┐
│ ADC     │  │ PID     │  │ HRPWM   │  │ Sleep   │
│ @20µs   │─►│ @10µs   │─►│ @5µs    │─►│ ~1.13ms │
└─────────┘  └─────────┘  └─────────┘  └─────────┘
                ↑
           CMPSS 同步检查 (保护)
```

### 9.5 软启动

```
每次模式切换或使能输出:
1. 目标值 = setpoint
2. 100 步斜坡 (116 ms)
3. 每步: current_target = target × (step / 100)
4. PID 输出限幅随斜坡递增
```

---

## 10. 固件架构

### 10.1 C2000 任务表 (FreeRTOS)

| 任务 | 优先级 | 周期 | 栈 (字) | 功能 |
|---|---|---|---|---|
| pid_task | 5 (最高) | 1.16ms (860Hz) | 512 | PID 运算 + HRPWM 更新 |
| protection_task | 4 | 1ms | 256 | 软件保护检查 |
| comm_task | 3 | 10ms (poll) | 512 | UART 帧处理 |
| housekeeping_task | 2 | 100ms | 256 | ADC 平均, LED, 日志 |

### 10.2 ESP32 任务表 (FreeRTOS)

| 任务 | 核心 | 优先级 | 功能 |
|---|---|---|---|
| uart_rx | 0 | 10 | UART 接收 + 帧解析 |
| ws_server | 1 | 5 | WebSocket 广播 @10Hz |
| http_server | 1 | 4 | REST API |
| display_tick | 1 | 3 | LVGL @30Hz |
| encoder_scan | 0 | 2 | 编码器 + 按键 |
| wifi_mgr | 0 | 1 | Wi-Fi 重连 |

### 10.3 文件结构

```
firmware/
├── c2000/                      # C2000 F28E12x 固件
│   ├── CMakeLists.txt
│   ├── FreeRTOSConfig.h
│   ├── main.c                  # 入口 + 任务创建
│   ├── control/
│   │   ├── pid.c/h             # PID 控制器实现
│   │   ├── current_loop.c/h    # 电流环封装
│   │   ├── voltage_loop.c/h    # 电压环封装
│   │   └── modes.c/h           # 模式管理
│   ├── drivers/
│   │   ├── adc.c/h             # ADC 驱动 (13ch 交错)
│   │   ├── hrpwm.c/h           # HRPWM 驱动 (150ps)
│   │   ├── cmpss.c/h           # CMPSS 比较器
│   │   ├── gpio.c/h            # GPIO 控制
│   │   ├── timer.c/h           # 定时器
│   │   └── uart.c/h            # UART 驱动
│   └── tasks/
│       ├── pid_task.c          # PID 任务 (860Hz)
│       ├── protection_task.c   # 保护任务 (1kHz)
│       ├── comm_task.c         # 通信任务
│       └── housekeeping_task.c # 后台任务
├── esp32/                      # ESP32-S3 固件
│   ├── CMakeLists.txt
│   └── main/
│       ├── app_main.c          # 入口
│       ├── uart_comms.c/h      # UART 协议
│       ├── webserver.c/h       # REST API
│       ├── websocket.c/h       # WebSocket
│       ├── display.c/h         # LVGL UI
│       ├── encoder.c/h         # 编码器
│       └── keypad.h            # 按键定义
├── common/
│   ├── el1000_types.h          # 共享类型
│   └── protocol.h              # 协议定义
├── scripts/
│   └── pid_sim.py              # PID 仿真
└── docs/
    └── arch.md                 # 固件架构文档
```

### 10.4 数据流

```
控制路径 (C2000 内部, 860Hz):
  ADC(13ch) → pid_task → HRPWM → MOSFET Gate
       ↑          │
       └── protection_task ←──┘ (故障时 TZ trip)

遥测路径 (C2000 → ESP32, 100ms):
  housekeeping → ringbuf → comm → UART → ESP32
                                            ↓
                                    WebSocket / LVGL / REST

命令路径 (ESP32 → C2000):
  UI/API/WebSocket → ESP32 comm → UART → C2000 comm
                                            ↓
                                     Mode/Setpoint
```

---

## 11. 外观结构

### 11.1 机箱规格

| 参数 | 值 |
|---|-----|
| 外形尺寸 | W310 × D370 × H120 mm |
| 颜色 | RAL 7021 (深灰) + 青绿 #00a884 |
| 材质 | 1.2mm SGCC 镀锌板 |
| 前面板 | 4mm 铝板, 拉丝氧化 |
| 重量 | ~5 kg |

### 11.2 前面板布局

```
┌──────────────────────────────────────────────────────────────┐
│  ┌──────────────────────────────────────────────────────┐    │
│  │                   4.3" IPS 彩屏                       │    │
│  │         (LVGL, 暗色主题, 实时数据显示)                │    │
│  └──────────────────────────────────────────────────────┘    │
│                                                              │
│  ┌─────┐ ┌─────┐ ┌─────┐ ┌─────┐      ┌────────┐ ┌──────┐ │
│  │ CC  │ │ CV  │ │ CR  │ │ CW  │      │ 旋钮   │ │ 接线 │ │
│  │     │ │     │ │     │ │     │      │(编码器)│ │ 柱   │ │
│  └─────┘ └─────┘ └─────┘ └─────┘      └────────┘ │ 红黑 │ │
│                                    ┌────────┐     └──────┘ │
│                                    │ 数字键盘│              │
│                                    └────────┘              │
│  ┌─────┐ ┌─────┐ ┌─────┐ ┌─────┐                          │
│  │ Menu│ │Enter│ │Esc  │ │On/Off│                          │
│  └─────┘ └─────┘ └─────┘ └─────┘                          │
└──────────────────────────────────────────────────────────────┘
```

### 11.3 后面板布局

```
┌──────────────────────────────────────────────────────────────┐
│   ┌─────┐   ┌──────┐   ┌────────┐   ┌──────┐   ┌──────┐   │
│   │IEC  │   │ USB  │   │ LAN    │   │ FAN  │   │ 急停  │   │
│   │电源 │   │ Type-C│   │ RJ45   │   │(120mm)  │(红色) │   │
│   │插座 │   │      │   │        │   │       │   │      │   │
│   └─────┘   └──────┘   └────────┘   └──────┘   └──────┘   │
│                                                              │
│               ┌──────────────────────┐                       │
│               │   散热出风口 (120mm) │                       │
│               │   + 把手             │                       │
│               └──────────────────────┘                       │
└──────────────────────────────────────────────────────────────┘
```

---

## 12. 整机 BOM

### 12.1 汇总

| 成本项 | 金额 (¥) | 占比 |
|---|---|---|
| 功率级 | 238 | 17.6% |
| 控制电路 | 196 | 14.5% |
| 电源树 | 148 | 10.9% |
| 安全防护 | 78 | 5.8% |
| 散热系统 | 216 | 15.9% |
| 机箱/外壳 | 175 | 12.9% |
| 连接器 | 51 | 3.8% |
| PCB 制板 | 75 | 5.5% |
| 组装 | 130 | 9.6% |
| 包装 | 31 | 2.3% |
| 配件 | 16 | 1.2% |
| **整机总计** | **¥1,354** | **100%** |

### 12.2 毛利率

| 项目 | 金额 |
|---|---|
| 整机 BOM 成本 | ¥1,354 |
| 目标零售价 (范围) | ¥3,999–5,999 |
| BOM 毛利率 | 66%–77% |
| 预估整体毛利率 (含费用) | 40%–55% |

### 12.3 降本路径

| 措施 | 单台节省 | 500台后 BOM |
|---|---|---|
| M90N20 批量 ¥10→¥8 | ¥24 | ¥1,330 |
| 散热器优化 ¥80→¥55 | ¥25 | ¥1,305 |
| 机箱模具分摊 ¥175→¥90 | ¥85 | ¥1,220 |
| PCB 批量 ¥75→¥40 | ¥35 | ¥1,185 |
| SMT 批量拼板 ¥60→¥25 | ¥35 | ¥1,150 |
| 包装批量 ¥15→¥8 | ¥7 | ¥1,143 |
| **批量 500 台合计** | **~¥211** | **¥1,054** |

---

## 13. 关键接口定义

### 13.1 电气接口

**输入 (DUT 侧)**:
```
DUT+ ────── 红色 4mm 镀金香蕉座 (30A)
DUT- ────── 黑色 4mm 镀金香蕉座 (30A)
Sense+ ──── 红色 2mm 香蕉座 (Kelvin 远端采样)
Sense- ──── 黑色 2mm 香蕉座 (Kelvin 远端采样)
```

**电源接口**:
```
AC 输入 ──── IEC C14 插座 (含保险丝座 10A/250V)
```

**通信接口**:
```
USB ──────── Type-C (USB 2.0 CDC, 虚拟串口)
LAN ──────── RJ45 (预留, Wi-Fi 优先)
CAN ──────── DB9 (隔离 CAN 2.0B)
```

### 13.2 控制接口

```
急停 ─────── 红色蘑菇头按钮 (常闭触点, 串联继电器线圈)
风扇 ─────── 4P PWM 端子 (12V/PWM/Tacho/GND)
```

### 13.3 固件接口 (C2000 ↔ ESP32)

参见第 8 节 UART 协议。注意:
- C2000 是 **从设备** (Wait-for-command)
- ESP32 是 **主设备** (发起所有事务)
- C2000 最长响应时间 **1ms**
- ESP32 轮询间隔 **10ms** (默认)
- WebSocket 推送间隔 **100ms** (10 Hz telemetry)

---

## 14. 测试验证方案

### 14.1 三阶段测试

| 阶段 | 内容 | 预算 | 周期 |
|---|---|---|---|
| **Phase 1** — 原型验证 | 面包板 + 开发板, 单管 MOSFET, PID 算法验证 | ¥550 | W8-W10 |
| **Phase 2** — 子卡验证 | 控制板 + 功率子板, 12 管, 满功率测试 | ¥1,000 | W11-W14 |
| **Phase 3** — 整机验证 | 完整样机, 安规/EMC/可靠性 | ¥500 | W15-W18 |

### 14.2 Phase 1 原型验证

```
设备清单:
- C2000 LaunchPad F28E12x (¥250)
- 单管 M90N20 + 散热器 (¥50)
- 面包板 + 阻容 (¥50)
- 辅助电源 48V/5A (¥100)
- 电阻负载 0.5Ω/200W (¥100)

验证项目:
1. PID 算法闭环 (CC 模式, 0→10A 阶跃)
2. HRPWM 输出验证 (25kHz, 150ps)
3. ADC 采样精度 (12bit, 13 通道交错)
4. CMPSS 硬件保护 (<1µs 响应)
5. UART 通信帧协议
```

### 14.3 安规认证策略

| 阶段 | 认证项 | 预算 | 说明 |
|---|---|---|---|
| 原型 | 自测绝缘/耐压 | ¥500 | 耐压仪租借 |
| 初期量产 | CE (LVD+EMC) | ¥27-45k | W20-W24 |
| 大批量 | CE + FCC | ¥88-155k | 第三方机构 |

---

## 附录 A: 版本历史

| 版本 | 日期 | 变更 | 编制人 |
|---|---|---|---|
| v1.0 | 2026-06-01 | 初稿 — 整合全部子系统设计 | — |

## 附录 B: 引用文档

| 编号 | 名称 | 版本 |
|---|---|---|
| SRD | 产品规格书 | v1.3 |
| SYS-ARCH-000 | 系统框图 | v1.1 |
| SYS-ARCH-001 | 安全架构 | v1.2 |
| SYS-ARCH-002 | 电源树架构 | v1.1 |
| SYS-ARCH-003 | 功率拓扑 | v1.0 |
| SYS-ARCH-004 | 控制架构 | v1.0 |
| SYS-ARCH-005 | 通信协议 | v1.0 |
| SYS-ARCH-006 | 外观结构 | v3 |
| SYS-ARCH-007 | 热设计报告 | v1.0 |
| SYS-SCH-001 | 功率级原理图设计说明 | v0.4 |
| SYS-SCH-002 | 控制电路原理图设计说明 | v0.1 |
| SYS-SCH-003 | 电源树原理图设计说明 | v0.1 |
| SYS-CTRL-001 | 控制算法设计说明 | v0.1 |
| SYS-BOM-001 | 整机BOM成本核算 | v0.1 |
| SYS-QA-001 | 安规认证策略 | v0.1 |
| SYS-TEST-001 | 快速原型验证策略 | v0.1 |
| SYS-SUP-001 | 供应链摸底框架 | v0.1 |

---

*文档结束 — SYS-TECH-001 v1.0*

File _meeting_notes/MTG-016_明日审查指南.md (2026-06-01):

# 📋 明日审查指南 — Codex生成文档
> 打开时间: 2026-06-01 (周一)
> 会话: MTG-016 系统修复 + Codex评估对应

---

## 审查顺序（建议从上到下）

### 第一部分：核心代码（最高优先级）

| 文件 | 路径 | 行数 | 审查重点 |
|---|---|---|---|
| PID控制器 | `06_软件研发/firmware/c2000/control/pid.c` | 96 | anti-windup逻辑、积分限幅0.95 |
| HRPWM驱动 | `06_软件研发/firmware/c2000/drivers/hrpwm.c` | 107 | TBPRD/TBCTL/DBCTL配置TODO |
| ADC驱动 | `06_软件研发/firmware/c2000/drivers/adc.c` | 86 | 13通道交错采样 |
| 主入口 | `06_软件研发/firmware/c2000/main.c` | 153 | 4个FreeRTOS任务+3个队列 |
| 电流环路 | `06_软件研发/firmware/c2000/control/current_loop.c` | 72 | 软启动斜坡逻辑 |
| ESP32入口 | `06_软件研发/firmware/esp32/main/app_main.c` | 86 | 子系统初始化顺序 |

### 第二部分：原理图（KiCad）

| 文件 | 路径 | 大小 | 审查重点 |
|---|---|---|---|
| 功率级(已恢复) | `05_硬件研发/原理图/KiCad/EL-1000_PowerStage.kicad_sch` | 1648行 | 12管M90N20阵列 + RS6332 + D882/B772 |
| 控制电路(新增) | `05_硬件研发/原理图/KiCad/EL-1000_ControlCircuit.kicad_sch` | 57KB | C2000最小系统 + ESP32 + ISO隔离 + LCD |
| 电源树(新增) | `05_硬件研发/原理图/KiCad/EL-1000_PowerTree.kicad_sch` | 60KB | AC输入→反激→3路Buck→LDO→电荷泵 |

> ⚠️ **提醒**: 需在 Windows KiCad 8 中打开，完善实际连线（生成脚本的wire是示意性）

### 第三部分：算法与仿真

| 文件 | 路径 | 审查重点 |
|---|---|---|
| 算法设计文档 | `06_软件研发/docs/SYS-CTRL-001_控制算法设计说明_v0.1.docx.md` | PID参数推导、模式切换、校准策略 |
| 仿真脚本 | `06_软件研发/firmware/scripts/pid_sim.py` | 运行: `~/.venv-power/bin/python pid_sim.py` |
| 仿真结果 | `06_软件研发/docs/pid_sim_results/` | 5张PNG: step/bode/nyquist/ki_sweep |

> **仿真关键发现**: 相位裕度109° 闭环带宽112Hz max_integral需≥0.88

### 第四部分：文档（略读即可）

| 文件 | 路径 | 核心结论 |
|---|---|---|
| 安规认证 | `07_测试验证/SYS-QA-001_安规认证策略_v0.1.md` | 两阶段: 初期¥27-45k / 量产¥88-155k |
| 整机BOM | `05_硬件研发/SYS-BOM-001_整机BOM成本核算_v0.1.md` | **¥1,354** (毛利率66-77%) |
| 供应链 | `08_供应链/SYS-SUP-001_供应链摸底框架_v0.1.md` | C2000🔴风险8-12周需立即下单 |
| 原型验证 | `07_测试验证/SYS-TEST-001_快速原型验证策略_v0.1.md` | 3阶段¥2,050总预算 |
| 问题跟踪 | `12_项目管理/ISSUES-001_项目问题跟踪清单_v0.1.md` | P1-P12遗留问题+优先级 |

---

## 待办事项（优先级排序）

| Pri | 事项 | 说明 |
|-----|---|---|
| 🔴 P0 | 在Windows KiCad 8中打开3张原理图完善连线 | 脚本生成wire是示意性 |
| 🔴 P0 | 打开pid_sim结果图看看效果 | `06_软件研发/docs/pid_sim_results/` |
| 🔴 P0 | 下单C2000 F28E12x样品 | 交期8-12周 |
| 🟡 P1 | 确认SGM71622R2价格或换GP8101 | 影响BOM准确性 |
| 🟡 P1 | 运行`pid_sim.py`看结果 | `~/.venv-power/bin/python pid_sim.py` |
| 🟢 P2 | git push (网络恢复后) | remote: kegaank/1000W_Electronic_Load |

---

## Git状态

```
29078eb W7: 系统问题修复完成 — 控制电路/电源树原理图 + 固件骨架 + 算法仿真
2435fd0 fix: pid.c max_integral 0.5→0.95
尚未推送: 2个commit
```

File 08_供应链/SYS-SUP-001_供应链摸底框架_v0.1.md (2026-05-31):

# SYS-SUP-001 供应链摸底框架 v0.1

**项目**: EL-1000 1000W 可编程直流电子负载  
**版本**: v0.1  
**日期**: 2026-05-31  
**状态**: 初稿

---

## 1. 采购策略总览

### 1.1 按阶段采购策略

| 阶段 | 数量 | 采购模式 | 供应商类型 | 周期要求 |
|---|---|---|---|---|
| 原型验证 (Phase 1-3) | 1–5 台 | 零售/小批 | 立创 LCSC / Mouser / Digikey / 淘宝 | 1–2 周 |
| 小批量试产 | 50–200 台 | 小批量直采 | LCSC / 1688 / 代理商 | 4–6 周 |
| 量产 (首批) | 200–500 台 | 批量直采 + 期货 | 原厂代理 (Arrow / Avnet / 世强 / 中电) | 8–12 周 |
| 稳定量产 | >500 台/年 | 期货 + VMI | 原厂代理 + 现货商备货 | 按季度排产 |

### 1.2 供应商分级

| 级别 | 类型 | 代表供应商 | 适用场景 |
|---|---|---|---|
| **T1** 原厂/一级代理 | 原厂授权分销商 | Arrow, Avnet, Future, Digikey, Mouser | 关键 IC (TI, ST) |
| **T2** 国内授权代理 | 国内授权渠道 | 中电港 (CECport), 世强 (Sekorm), 力源 (P&S) | 批量采购 TI / onsemi |
| **T3** 现货/平台 | 现货分销平台 | LCSC (立创), 1688, 淘宝 | 阻容/通用件/小批量 |
| **T4** 国产替代渠道 | 直接联系原厂 | 圣邦微 (SGM), 迈诺斯 (MINOS), 开步睿思 | 国产化降本 |

---

## 2. 关键 IC 供应评估

### 2.1 MOSFET — M90N20

| 参数 | 信息 |
|---|---|
| **品牌** | MINOS (迈诺斯) — 台系/国产, IDM 模式 |
| **替代方案** | IRFP260NPbF (Infineon), IXFN90N20 (IXYS), NTHL090N65S3H (onsemi) |
| **MOQ** | 50–100 (LCSC) / 500 (原厂) |
| **单价** | ¥8–12/颗 (批量 100+) |
| **交期 (LT)** | 4–8 周 (原厂) / 现货 (LCSC) |
| **供应风险** | 低 — 多品牌兼容, TO-247 封装标准件 |
| **建议动作** | 原型用 LCSC 现货, 量产前签 MINOS 代理协议 |

### 2.2 MCU — C2000 F28E12x (或 F280013x)

| 参数 | 信息 |
|---|---|
| **品牌** | Texas Instruments (TI) |
| **替代方案** | STM32G4 (HRTIM) — 需重构代码; AT32F435 (雅特力) — 无 HRPWM |
| **MOQ** | 160–250 (代理), 1 (Mouser/LCSC) |
| **单价** | ¥60–80 (F28E12x) / ¥35–50 (F280013x) |
| **交期 (LT)** | 8–12 周 (代理期货) / 现货 (Mouser 有货) |
| **供应风险** | **中高** — TI 在 2021-2023 有过严重缺货, 目前好转但仍需提前锁定 |
| **建议动作** | 原型: Mouser / Digikey 现货; 小批量: 立即从 Arrow / Avnet 下期货单 |

### 2.3 WiFi/蓝牙模块 — ESP32-S3-WROOM-1

| 参数 | 信息 |
|---|---|
| **品牌** | Espressif (乐鑫) |
| **替代方案** | ESP32-C3 (更低价), 或外部 WiFi 模块 (AT 指令) |
| **MOQ** | 1 (LCSC) |
| **单价** | ¥22–28 |
| **交期 (LT)** | 2–4 周 |
| **供应风险** | **低** — 乐鑫产能充足, LCSC 长期现货 |

### 2.4 反激控制器 — UCC28C45

| 参数 | 信息 |
|---|---|
| **品牌** | TI / onsemi (NCP1207 替代) |
| **替代方案** | NCP1207 (onsemi), UC3845 (多家国产) |
| **MOQ** | 1 (LCSC) |
| **单价** | ¥3–5 |
| **交期 (LT)** | 4–8 周 |
| **供应风险** | **低** — 成熟产品, 多品牌可替代 |

### 2.5 ADC — ADS1115IDGSR

| 参数 | 信息 |
|---|---|
| **品牌** | Texas Instruments (TI) |
| **替代方案** | MCP3421 (Microchip), 或 C2000 内部 12-bit ADC (精度妥协) |
| **MOQ** | 1 (LCSC) |
| **单价** | ¥7–10 |
| **交期 (LT)** | 4–6 周 |
| **供应风险** | **低** — 长期在产, 多家可替代 |

### 2.6 DAC — SGM71622R2

| 参数 | 信息 |
|---|---|
| **品牌** | SGM (圣邦微, 国产) |
| **替代方案** | DAC8552 (TI), MCP4922 (Microchip) |
| **MOQ** | 需圣邦微确认 (通常 100+) |
| **单价** | 待询价 (预计 ¥15–25) |
| **交期 (LT)** | 4–8 周 (原厂直供) |
| **供应风险** | **中** — 国产供应稳定但需建立联系, 备选方案充足 |

### 2.7 运放 — LM358 (MSKSEMI)

| 参数 | 信息 |
|---|---|
| **品牌** | MSKSEMI (美森科, 国产) |
| **替代方案** | LM358 (任何品牌), 或 SGM358 (圣邦微) |
| **MOQ** | 10+ |
| **单价** | ¥0.2–0.4 |
| **交期 (LT)** | 2–4 周 |
| **供应风险** | **极低** — 通用品, 遍地供应 |

---

## 3. 关键无源器件供应

| 器件 | 供应商 | 单价 | 交期 | 风险 |
|---|---|---|---|---|
| 检流电阻 MCSF2512DR050Q9 | 开步睿思 / LCSC | ¥0.82 | 现货 | 低, 唯一料但可代换 |
| 阻容 0805 / 1206 | LCSC / 国巨 / 三星 | ¥0.01–0.05 | 现货 | 极低 |
| AlN 绝缘垫 TO-247 | 淘宝 / LCSC / 晨日科技 | ¥3.00 | 现货 | 低, 氧化铝可替代 |
| 电解电容 (高压) | 尼吉康 / 红宝石 / 国产江海 | ¥2–8 | 4–8 周 | 低 |
| 变压器 (反激) | 定制 (顺络 / 麦捷 / 国产小厂) | ¥8–15 | 4–6 周 | 中, 需打样+交期 |

---

## 4. PCB 制造 & 组装

### 4.1 PCB 制板

| 阶段 | 供应商 | 周期 | 费用 | 说明 |
|---|---|---|---|---|
| 原型 (1–5 片) | **JLCPCB** (嘉立创) | 2–3 天 | ¥30–50/款 | 4层 2oz 铜, ENIG |
| 小批量 (50–200 pcs) | **华迅 / 华盛** | 5–7 天 | ¥15–25/片 | 按拼板计算 |
| 中批量 (200–1000 pcs) | **华迅 / 深南电路** | 7–10 天 | ¥8–15/片 | 可做阻抗控制 |
| 大批量 (>1000 pcs) | 深南 / 景旺 / 博敏 | 10–14 天 | ¥5–10/片 | — |

**PCB 技术规格**:
- 功率主板: 4 层, 2oz 铜内外层, FR4 TG170, ENIG, 100×160mm
- 控制板: 4 层, 1oz, FR4 TG150, ENIG, 80×100mm
- 电源板: 2 层, 2oz, FR4 TG150, HASL, 60×80mm

### 4.2 SMT 贴片组装

| 阶段 | 供应商 | 周期 | 费用 (¥/款) | 说明 |
|---|---|---|---|---|
| 原型 (1–5 pcs) | **嘉立创 SMT** (JLCSMT) | 1–2 天 | ¥100–200 | 含钢网, 全部立创库存料 |
| 小批量 (50–200 pcs) | **华迅 / 快装王** | 3–5 天 | ¥60–80 | 来料加工 |
| 中批量 (200–1000 pcs) | 华迅 / 本地 SMT 厂 | 5–7 天 | ¥30–50 | 拼板 + 减少换线 |

> **建议**: 原型采用 JLCSMT 全包服务（立创商城直发+贴片一体），小批量后转本地/华迅 SMT 降本。

---

## 5. 结构件供应

### 5.1 钣金机箱

| 阶段 | 供应商类型 | 周期 | 费用 | 说明 |
|---|---|---|---|---|
| 原型 (1–5 台) | 本地钣金作坊 / 淘宝 | 3–5 天 | ¥150–200/台 | 折弯+冲孔, 无模具 |
| 小批量 (50–200 台) | 本地钣金厂 | 7–14 天 | ¥80–120/台 | 可做简易模具(折弯模) |
| 量产 (>500 台/年) | 冲压模具厂 | 周期 2 周 (模具) + 2 周 (生产) | **模具 ¥3,000–5,000** + ¥50–70/台 | 连续冲压模 |

**推荐供应商清单**:

| 供应商 | 类型 | 优势 | 联系方式 |
|---|---|---|---|
| 本地钣金作坊 (深圳/东莞) | 折弯冲压 | 打样快速, 价格灵活 | 需实地走访 |
| 1688 钣金加工 | 平台接单 | 线上报价, 标准流程 | 搜索"钣金加工 机箱" |
| 华阳通 / 中兴新通讯 (大厂) | 专业钣金 | 质量可靠, 适合批量 | — |

### 5.2 前面板

| 工艺 | 供应商 | 周期 | 单价 (¥) | 说明 |
|---|---|---|---|---|
| 拉丝铝 + 丝印 | 本地标牌厂 | 3–5 天 | 25–40 | 原型/小批量 |
| 拉丝铝 + UV 打印 | 淘宝 / 标牌厂 | 5–7 天 | 30–50 | 小批量, 可彩印 |
| 冲压 + 氧化 + 镭雕 | 冲压厂 | 7–10 天 | 15–30 (模具另计) | 量产 |

---

## 6. 包装 & 辅材供应

| 物料 | 供应商 | 单价 (¥) | MOQ | 说明 |
|---|---|---|---|---|
| 彩盒 | 东莞/深圳纸品厂, 1688 | 8–15 | 500–1000 | 4C 彩印 + E 瓦 |
| 珍珠棉 (EPE) | 1688 / 本地包装厂 | 3–8 | 500+ | 定制模切 |
| 气泡袋 | 淘宝 / 1688 | 1–3 | 100+ | 防静电型 |
| 说明书/手册 | 本地快印店 | 3–5 | 50+ | 黑白双面 |
| 电源线 | 淘宝 / 线材厂 | 5–8 | 100+ | 国标/欧标/美标 |
| USB 数据线 | 淘宝 / 线材厂 | 3–5 | 100+ | Type-C |

---

## 7. 设备 & 工装投资

| 项目 | 用途 | 预算 (¥) | 来源 |
|---|---|---|---|
| 校准万用表 (6.5 位) | 出厂校准 + 研发 | 1,500–3,000 | 二手 Keysight/Fluke |
| 电子负载校准工装 | 批量出厂校准 | 500–1,000 | 自制 + 标准电阻 |
| ESD 防护工位 | SMT 后焊 + 组装 | 500–1,000 | 静电手环 + 台垫 + 接地 |
| 烧录工装 | C2000 + ESP32 固件烧录 | 300–500 | 自制 + J-Link |
| 老化架 | 整机老化测试 (8 通道) | 2,000–3,000 | 自制 + 电阻负载 |
| 贴片钢网 (×3) | SMT 焊接 | 300–500 | 立创/华迅 |
| **合计** | | **¥5,100–9,000** | 一次投入, 后续复用 |

---

## 8. 供应风险矩阵

| 物料 | 风险等级 | 风险描述 | 缓解措施 |
|---|---|---|---|
| C2000 F28E12x | 🔴 **高** | TI 产能紧张, 缺货历史恶劣 | 提前 12 周下单; 备选 STM32G4 评估 |
| ESP32-S3-WROOM-1 | 🟢 低 | 乐鑫产能充足 | 关注模块版本升级 |
| M90N20 (MINOS) | 🟡 中 | 国内品牌, 渠道不成熟 | 锁定现货; 备选 IRFP260N / IXFN90N20 |
| 反激变压器 (定制) | 🟡 中 | 定制件, 打样周期长 | 提前启动; 标准磁芯+绕线厂 3 家备选 |
| AlN 绝缘垫 | 🟢 低 | 多品牌替代 | 备选 Al₂O₃ / TGP |
| 钣金机箱 | 🟡 中 | 模具费用 + 交期 | 原型先手工折弯; 备选 2–3 家钣金厂 |
| ADS1115 (TI) | 🟢 低 | 通用料, 多来源 | MCP3421 替代 |

**风险等级**: 🔴 高 = 预计需 >1 月前置期或唯一来源 | 🟡 中 = 需关注交期 | 🟢 低 = 充足供应

---

## 9. 供应商联系清单 (模板)

| 物料 | 供应商 | 联系人 | 电话/微信 | 邮箱 | 状态 |
|---|---|---|---|---|---|
| M90N20 | MINOS (迈诺斯) | — | — | — | 待联系 |
| C2000 | TI (Arrow) | — | — | — | 待联系 |
| ESP32-S3 | LCSC | — | — | — | 快捷下单 |
| DAC SGM71622 | 圣邦微 (SGM) | — | — | — | 待询价 |
| 钣金机箱 | 本地厂 A | — | — | — | 待洽谈 |
| PCB | 华迅 | — | — | — | 待打样 |
| SMT | 嘉立创 SMT | — | — | — | 可在线下单 |

> *联系方式请 PM 在供应链摸底阶段补充。*

---

## 10. 下一步行动计划

| 任务 | 负责人 | 优先级 | 截止时间 | 状态 |
|---|---|---|---|---|
| 联系 MINOS 获取 M90N20 批量报价 | 采购 | P0 | W8 | 🔴 待启动 |
| 联系圣邦微获取 SGM71622R2 样品+报价 | 硬件 | P0 | W7 | 🔴 待启动 |
| 从 Arrow/Avnet 询 C2000 期货交期+价 | 采购 | P0 | W7 | 🔴 待启动 |
| 钣金机箱 3 家报价 (原型) | 结构 | P1 | W8 | 🔴 待启动 |
| PCB 原型打样 (JLCPCB) | 硬件 | P1 | W7 | 🔴 待启动 |
| 本地 SMT厂询价 (小批量) | 采购 | P2 | W10 | 🔴 待启动 |
| 变压器供应商联系 | 硬件 | P1 | W8 | 🔴 待启动 |

---

**版本历史**

| 版本 | 日期 | 变更内容 | 编制人 |
|---|---|---|---|
| v0.1 | 2026-05-31 | 初稿 — 供应框架搭建 | — |

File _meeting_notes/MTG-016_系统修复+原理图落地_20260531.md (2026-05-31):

# MTG-016 项目系统修复 + 控制电路/电源树原理图落地 2026-05-31

## 参会人
- 创始人（执行合伙人）
- AI Hermes

## 背景
Codex对EL-1000项目进行了全面评估（7.5/10分），识别出10项问题：
🔴 严重问题3项、🟠 较严重3项、🟡 次要4项。
本会话将问题全部修复或启动。

## 修复清单

### 1. 功率级原理图
- **问题**: 工作树被gen_sch.py覆盖清空（23行骨架→1648行内容丢失）
- **修复**: `git checkout HEAD -- EL-1000_PowerStage.kicad_sch` 恢复
- **验证**: kicad-cli可解析输出XML，含54个符号

### 2. 控制电路 KiCad 原理图 (NEW)
- **输入**: `SYS-SCH-002_控制电路原理图设计说明_v0.1.docx`
- **输出**: `EL-1000_ControlCircuit.kicad_sch` (57KB, 92元件)
- **内容**: C2000最小系统(晶振/JTAG/复位/退耦)、ESP32-S3模组、SGM71622R2 DAC、ADS1115 ADC、ISO7741隔离、ADuM1201/3160隔离、AMS1117 LDO、LCD连接器、编码器、按键矩阵、看门狗TPS3823
- **生成脚本**: `gen_ctrl_sch.py`

### 3. 电源树 KiCad 原理图 (NEW)
- **输入**: `SYS-SCH-003_电源树原理图设计说明_v0.1.docx`
- **输出**: `EL-1000_PowerTree.kicad_sch` (60KB, 65元件)
- **内容**: AC输入(EMI+NTC+泄放)、整流+母线电容、反激UCC28C45(COMP/CS/RTCT/OUT/VCC/VREF)、Buck1 +15V/1A(IRF9540)、Buck2 +12V/2A(自举)、Buck3 +5V/3A(自举)、LDO AMS1117-3.3、-15V电荷泵
- **生成脚本**: `gen_psu_sch.py`
- ⚠️ **注意**: 需在KiCad GUI中完善实际连线（脚本生成wire为示意性）

### 4. 控制算法设计文档 + PID仿真
- **文档**: `06_软件研发/docs/SYS-CTRL-001_控制算法设计说明_v0.1.docx.md`
- **仿真脚本**: `06_软件研发/firmware/scripts/pid_sim.py`
- **结果**: 5张分析图(阶跃响应/放大/Bode/Nyquist/Ki扫描)
- **关键发现**: 12×M90N20 跨导 ~120S, 相位裕度 109°, 闭环带宽 ~112Hz
- **发现的问题**: 固件中 max_integral=0.5 太保守，需≥0.95

### 5. 固件骨架 (39文件)
- **路径**: `06_软件研发/firmware/`
- **结构**: c2000/ (main+drivers+control+tasks) + esp32/ (main+components) + common/ + docs/
- **关键文件**: pid.c(反饱和积分的PID), hrpwm.c(25kHz HRPWM+MEP), adc.c(13ch扫描), cmpss.c(硬件比较器)
- ⚠️ **缺失4个文件**: protocol.c, wifi.h, wifi.c, data_log.c（迭代限制）

### 6. 安规认证策略
- **文档**: `07_测试验证/SYS-QA-001_安规认证策略_v0.1.md`
- **关键结论**: 2层策略——初期CE自声明+FCC SDoC(~¥27-45k), 量产全认证(~¥88-155k)
- **建议**: PCB布局阶段按EMI设计规范做，减后续认证返工

### 7. 整机BOM成本核算
- **文档**: `05_硬件研发/SYS-BOM-001_整机BOM成本核算_v0.1.md`
- **原有合计**: 功率级¥238 + 控制¥196 + 电源¥148 + 安全¥78 + 散热¥216 = ¥876
- **新增项**: 外壳¥175 + 连接器¥51 + PCB¥75 + 组装¥130 + 包装¥31 + 附件¥16 = ¥478
- **合计**: **¥1,354** (占零售¥3,999-5,999的22-34%, 毛利充足)
- **批量路径**: 200台→¥1,143, 500台→¥1,054

### 8. 供应链摸底
- **文档**: `08_供应链/SYS-SUP-001_供应链摸底框架_v0.1.md`
- **关键发现**: C2000 F28E12x🔴高风险(8-12周), ESP32-S3🟢低风险(2-4周)
- **备选方案**: STM32G4系列作为C2000替代

### 9. 快速原型验证策略
- **文档**: `07_测试验证/SYS-TEST-001_快速原型验证策略_v0.1.md`
- **3阶段**: Phase1(单管100W, ¥350) → Phase2(4管400W) → Phase3(12管1000W, ¥1,200)
- **预算**: 8周总计¥2,050

### 10. .gitignore优化
- 添加 `~$*` 临时文件过滤
- 添加 KiCad 备份过滤
- 注释提示生成原理图是否纳入版本控制

## 交付物清单
| 交付物 | 路径 | 类型 |
|---|---|---|
| 问题跟踪清单 | 12_项目管理/ISSUES-001_项目问题跟踪清单_v0.1.md | 文档 |
| 控制电路原理图 | 05_硬件研发/原理图/KiCad/EL-1000_ControlCircuit.kicad_sch | 原理图 |
| 控制电路生成脚本 | 05_硬件研发/原理图/KiCad/gen_ctrl_sch.py | 脚本 |
| 电源树原理图 | 05_硬件研发/原理图/KiCad/EL-1000_PowerTree.kicad_sch | 原理图 |
| 电源树生成脚本 | 05_硬件研发/原理图/KiCad/gen_psu_sch.py | 脚本 |
| 控制算法设计文档 | 06_软件研发/docs/SYS-CTRL-001_控制算法设计说明_v0.1.docx.md | 文档 |
| PID仿真脚本 | 06_软件研发/firmware/scripts/pid_sim.py | 脚本 |
| PID分析图(5张) | 06_软件研发/docs/pid_sim_results/*.png | 图表 |
| 固件骨架(39文件) | 06_软件研发/firmware/ | 代码 |
| 安规认证策略 | 07_测试验证/SYS-QA-001_安规认证策略_v0.1.md | 文档 |
| 整机BOM核算 | 05_硬件研发/SYS-BOM-001_整机BOM成本核算_v0.1.md | 文档 |
| 供应链摸底 | 08_供应链/SYS-SUP-001_供应链摸底框架_v0.1.md | 文档 |
| 原型验证策略 | 07_测试验证/SYS-TEST-001_快速原型验证策略_v0.1.md | 文档 |
| 本会议纪要 | _meeting_notes/MTG-016_系统修复+原理图落地_20260531.md | 纪要 |

## 待办 (用户)
- [ ] 在Windows KiCad 8中打开控制电路/电源树原理图，完善实际连线
- [ ] 为所有元件分配Footprint封装
- [ ] 确认DAC方案(SGM71622R2 vs GP8101)
- [ ] 下单C2000 F28E12x样品(交期8-12周)
- [ ] 预览PID仿真结果图并反馈(tuning建议)
- [ ] git add + commit + push

## Git状态
当前有大量未跟踪文件，建议运行 `git status` 审查后提交命名为:
`W7: 系统修复完成: 控制电路/电源树原理图 + 固件骨架 + 算法仿真 + 认证/BOM/供应链文档`

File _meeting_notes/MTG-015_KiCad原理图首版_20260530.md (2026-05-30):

# MTG-015 KiCad原理图首版生成 + 桌面自动化 2026-05-30

## 参会人
- 创始人（执行合伙人）
- AI Hermes

## 背景
W7硬件研发阶段：功率级原理图已到v0.4设计说明阶段，需要落地为KiCad实际原理图文件。

## 决定
1. **DAC方案**: HRPWM+RC滤波(10kΩ+1μF, ¥0, 等效15.2bit)替代独立DAC芯片
2. **运放**: RS6332(润石, Vos=0.8mV, ¥0.50)替代LM358，精度从±2.5%改善到±0.6%
3. **桌面自动化**: 使用pyautogui+python-xlib实现X11窗口控制，创建了desktop-automation skill
4. **KiCad原理图格式**: s-expression格式，不使用(extends)继承符号
   - LM358/2N7002等带extends的符号不可用，需改用基类

## 已交付物
- `SYS-SCH-001_功率级原理图设计说明_v0.4.docx` — 运放RS6332升级+HRPWM方案
- `EL-1000_PowerStage.kicad_pro` — KiCad项目文件
- `EL-1000_PowerStage.kicad_sch` (34KB, 1102行) — 功率级原理图
  - HRPWM RC滤波 + 1/13.2分压
  - RS6332运放 + D882/B772推挽驱动
  - 12×M90N20 MOSFET阵列（2组×6管）
  - 12×MCSF2512DR050Q9 源极电阻
  - 6路GND、3路电源符号
- `desktop-automation` skill + `x11_control.py` — X11桌面自动化工具
- `build_full.py` — .kicad_sch生成脚本（可复用）
- 功率级BOM: ~¥213

## 待办
- [ ] 网络恢复后 `git push`（3个本地commit待推送）
- [ ] 在KiCad GUI中完善连线（当前版本只有元件放置，需手动加wire和net label）
- [ ] 画控制电路、电源树原理图

## Git本地状态
```
0a9b873  功率级原理图v0.4: RS6332+HRPWM
b7b7be4  电源树原理图 v0.1
36a575f  控制电路原理图 v0.1
```

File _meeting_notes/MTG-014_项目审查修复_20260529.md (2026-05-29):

# MTG-014 项目资料系统性审查与修复 2026-05-29

## 参会人
- 创始人（执行合伙人）
- AI Hermes

## 工作内容
### 1. 03_系统设计 — 系统框图 (SYS-ARCH-000)
- 新建 `03_系统设计/系统框架/SYS-ARCH-000_系统框图_v1.0.svg`
- 六大区域: 辅助电源树 / 主功率级 / 控制与采样 / 通信与UI / 安全架构 / 图例
- 完整功率路径: DUT → 端子 → 继电器 → 熔丝 → MOSFET阵列 → 检流 → GND

### 2. 03_系统设计 — 热设计报告 (SYS-ARCH-007-H)
- 新建 `03_系统设计/热设计/SYS-ARCH-007-H_热设计报告_v1.0.docx` + 热性能曲线图
- 关键结论: 350×150×50mm铝挤压散热器 + 双120mm高速PWM风扇
- 目标θSA ≤ 0.06°C/W, 推荐12管量产 (Tj=122°C@Ta=25°C)
- 风险: Spirito效应 → 需原型实测, 备选IRFP460/IXFH52N30P

### 3. 12_项目管理 — SDR评审材料包 (SDR-001)
- 新建 `12_项目管理/评审材料/W6_SDR评审/SDR-001_SDR评审材料包_v1.0.docx`
- 含评审议程/决策清单/BOM成本汇总(整机~¥864)/风险登记册/检查表/开放问题

### 4. 项目资料系统性审查
通读 02_产品定义 → 03_系统设计(7子模块) → 04_外观结构 → 12_项目管理的全部资料, 发现11个跨文档不一致:

#### 🔴 严重 (全部修复)
1. MOSFET管数不一致 (8管 vs 12管) → 统一12管
2. SRD规格书架构脱节 (STM32→C2000, IRFP→M90N20, 外置48V→AC反激) → 发布SRD v1.3
3. 外形尺寸矛盾 (260×320×110 vs 310×370×120) → SRD v1.3统一

#### 🟠 较严重 (全部修复)
4. SVG栅极驱动标错 (UCC27524→OPA548)
5. SVG反激控制方式矛盾 (UCC28C45→C2000数字直驱)
6. OPA548数量 (8只→2只)
7. θSA/BOM数据同步

#### 🟡 次要 (待后续)
8. ID文档风扇80mm→热设计120mm
9. 功率额定统一为1000W连续/1500W峰值
10. 项目代号统一为EL-1000

### 5. SRD v1.3 发布
- 文件名: `02_产品定义/SRD_EL-1000_产品规格书_v1.3.docx`
- 10项架构修正, 统一项目命名为 EL-1000
- 保留v1.0-v1.2供追溯

### 6. 系统框图SVG修复 (v1.0→v1.1)
- 6处修补: 12管/OPA548×2/反激C2000数字直驱/θSA 0.06°C/W/BOM~¥300

## 已交付物
| 交付物 | 路径 | 说明 |
|---|---|---|
| 系统框图 SVG | 03_系统设计/系统框架/SYS-ARCH-000_系统框图_v1.1.svg | 整机架构总图 |
| 热设计报告 docx | 03_系统设计/热设计/SYS-ARCH-007-H_热设计报告_v1.0.docx | 含风扇选型/降额/PWM策略 |
| 热性能曲线 PNG | 03_系统设计/热设计/SYS-ARCH-007-H_thermal_curves.png | 4张分析图 |
| SDR评审包 docx | 12_项目管理/评审材料/W6_SDR评审/SDR-001_SDR评审材料包_v1.0.docx | 完整SDR材料 |
| SRD v1.3 docx | 02_产品定义/SRD_EL-1000_产品规格书_v1.3.docx | 架构对齐更新 |
| 会议纪要 md | _meeting_notes/MTG-014_项目审查修复_20260529.md | 本文件 |

## 下阶段待办
- [ ] ID-SPEC-001 风扇尺寸/后面板布局更新 (80→120mm)
- [ ] 项目排期表尺寸同步
- [ ] 进入05_硬件研发 (W7-W14)

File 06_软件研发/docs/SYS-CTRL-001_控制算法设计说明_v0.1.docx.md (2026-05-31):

# SYS-CTRL-001 控制算法设计说明 v0.1

> **项目**: EL-1000 1000W 可编程电子负载
> **日期**: 2026-05-31
> **状态**: Draft
> **负责人**: 固件团队

---

## 1. 文档概述

### 1.1 目的
本文档描述 EL-1000 电子负载的控制算法架构、PID 算法实现、环路参数推导、模式切换逻辑、保护集成及校准策略。

### 1.2 参考文档
| 文档编号 | 名称 |
|---|---|
| SYS-SCH-001 | 功率级原理图设计说明 v0.4 |
| SYS-SCH-002 | 控制电路原理图设计说明 v0.1 |
| — | firmware/docs/arch.md (固件架构) |
| — | pid.h / pid.c (PID实现) |
| — | current_loop.h/.c (电流环路) |
| — | voltage_loop.h/.c (电压环路) |

### 1.3 缩写
| 缩写 | 说明 |
|---|---|
| CC | Constant Current (恒流模式) |
| CV | Constant Voltage (恒压模式) |
| CR | Constant Resistance (恒阻模式) |
| CW | Constant Power (恒功率模式) |
| HRPWM | High-Resolution PWM (高分辨率PWM) |
| CMPSS | Comparator Subsystem (比较器子系统) |
| MEP | Micro-Edge Positioner (微边沿定位器) |
| OCP | Over-Current Protection |
| OVP | Over-Voltage Protection |
| OTP | Over-Temperature Protection |
| OPP | Over-Power Protection |

---

## 2. 控制环路架构

### 2.1 总体框图

```
                    ┌─────────────────────────────────────────────┐
                    │              EL-1000 Control System          │
                    │                                              │
  Setpoint ────────►│  ┌─────────┐  ┌──────────┐  ┌───────────┐  │
  (I/V/R/P)         │  │  Mode   │  │  Outer   │  │  Inner    │  │
                    │  │ Select  │──►│  Loop    │──►│  Current  │──► PWM ──► MOSFETs
                    │  │         │  │  (V/R/P) │  │  Loop     │  │
                    │  └─────────┘  └──────────┘  └─────┬─────┘  │
                    │        ▲                           │        │
                    │        │  Voltage / Power FB       │ Current│
                    │        └───────────────────────────┤ FB    │
                    │                                    │        │
                    │  ┌──────────┐  ┌──────────┐        │        │
                    │  │ CMPSS    │  │ SW       │        │        │
                    │  │ HW Trip  │  │ Protection│        │        │
                    │  └──────────┘  └──────────┘        │        │
                    └────────────────────────────────────┴────────┘
```

### 2.2 环路层次

| 环路 | 类型 | 更新率 | 输出 | 应用模式 |
|---|---|---|---|---|
| 内环 — 电流环 | PI (并联式) | 860 Hz | 占空比 → HRPWM | CC, CV, CR, CW |
| 外环 — 电压环 | PI (并联式) | 860 Hz | 电流给定 → 内环 | CV |
| 外环 — 功率环 | PI (并联式) | 860 Hz | 电流给定 → 内环 | CW (规划中) |
| 外环 — 电阻环 | PI (并联式) | 860 Hz | 电流给定 → 内环 | CR (规划中) |

### 2.3 级联控制策略

CV/CR/CW 模式使用 **级联控制** 结构：
- **外环** (电压/功率/电阻) 输出电流给定值 (I_demand)
- **内环** (电流) 快速跟踪该给定值
- 内环带宽 ≫ 外环带宽 (典型比值为 5:1 至 10:1)

优势：
- 内环快速响应电流扰动，保护 MOSFET
- 外环可独立设计，无需担心电流环稳定性
- 自然实现限流保护 (外环输出限幅)

---

## 3. PID 算法实现

### 3.1 算法形式：并联式 (Parallel Form)

采用 **测量值微分 (Derivative on Measurement)** 的并联式 PID：

```
error[n]     = setpoint - measurement[n]
p_term[n]    = Kp × error[n]
i_term[n]    = i_term[n-1] + Ki × error[n] × dt
d_term[n]    = -Kd × (measurement[n] - measurement[n-1]) / dt
output[n]    = p_term[n] + i_term[n] + d_term[n]
output[n]    = clamp(output[n], min_output, max_output)
```

**传递函数 (连续域)**:

```
            ┌         1             s·Td ┐
Gc(s) = Kp ·│ 1 + ──────── + ──────────── │
            └       s·Ti       1 + s·Td/N ┘
```

离散化采用 **前向欧拉法** (Forward Euler):
- s → (z-1)/Ts

### 3.2 抗饱和 (Anti-Windup)

采用 **积分钳位 (Integral Clamping)** 策略：

```
if output[n] >= max_output AND error[n] > 0:
    # 输出饱和且误差同向 — 冻结积分
    i_term[n] = i_term[n-1]  # 不累加
elif output[n] <= min_output AND error[n] < 0:
    # 输出饱和且误差反向 — 冻结积分
    i_term[n] = i_term[n-1]
else:
    i_term[n] = i_term[n-1] + Ki × error[n] × dt

# 辅助限幅：对积分项单独限幅
i_term[n] = clamp(i_term[n], max_integral, min_integral)
```

当前实现使用简化版：仅对积分项单独限幅 (±max_integral)，可防止大部分 windup 问题。待进一步调优。

### 3.3 输出限幅

| 环路 | min_output | max_output | 说明 |
|---|---|---|---|
| 电流环 | 0.0 | 0.95 | 占空比 (HRPWM 0-95%) |
| 电压环 | 0.0 | 110.0 | 电流给定 (A) |

### 3.4 微分项说明

当前电流环 Kd = 0.001 (接近零)，实际表现为 **PI 控制器**。
- 电流环：PI (Kd 接近零，测量值微分形式防止微分冲激)
- 电压环：PI (Kd = 0，纯 PI)

---

## 4. 采样策略

### 4.1 PID 时序 (860 Hz)

```
周期 T = 1/860 ≈ 1.163 ms

┌─────────┐    ┌─────────┐    ┌─────────┐    ┌─────────┐
│ ADC     │    │ PID     │    │ HRPWM   │    │ Sleep   │
│ Sample  │───►│ Compute │───►│ Update  │───►│ (剩余)  │
│ ~20 µs  │    │ ~10 µs  │    │ ~5 µs   │    │~1.13 ms │
└─────────┘    └─────────┘    └─────────┘    └─────────┘
```

### 4.2 ADC 交错采样 (ADC Interleaving)

C2000 F28E12x ADC 支持 13 通道采样。采样策略：
1. **SOC 触发**: ePWM1 时基触发 ADC SOC (860 Hz)
2. **通道序列**: Vload → Iload → Vref → Iref → Temp1..Temp4 → PSU → 保留
3. **交错模式**: 使用两个 ADC 内核 (A + B) 交错采样，等效采样率 1.72 kHz
4. **结果读取**: PID 任务等待所有通道转换完成 (EOC 中断)

### 4.3 HRPWM 同步

- HRPWM 频率: **25 kHz** (周期 40 µs)
- HRPWM 分辨率: **~150 ps** (MEP 步进)
- **同步策略**: PID 更新在 ePWM1 时基零交叉时写入新占空比，保证每个 PWM 周期占空比一致
- **RC 滤波器**: 10 kΩ + 1 µF (f_c ≈ 15.9 Hz)，将 PWM 转换为模拟参考电压 (等效 ~15.2 bit DAC)

---

## 5. PI 参数推导

### 5.1 电流环参数推导

#### 5.1.1 被控对象模型

**功率级**: 12 × M90N20 MOSFET + 12 × 0.050Ω 源极电阻

```
等效源极电阻: R_sense = 0.050Ω / 12 = 0.004167 Ω
MOSFET 转移特性: Id ≈ gm × Vgs (饱和区)
M90N20 典型 gm ≈ 20 S (在 Id ≈ 8A 时)
12 管并联等效: gm_total ≈ 12 × 20 = 240 S
```

**驱动级** (D882 + B772 推挽):
```
从 HRPWM 滤波输出 (Vdac) 到 MOSFET Vgs 的增益:
- HRPWM RC 滤波器: Vdac = D × 3.3V (D: 占空比 0~1)
- 推挽射极跟随器: Av ≈ 0.95 (压降约 0.15V)
- Vgs = 0.95 × D × 3.3V
```

**电流检测** (RS6332 差分放大器):
```
假设电流检测差分放大增益: A_i_sense = 10
Vsense = I_load × R_sense × A_i_sense = I_load × 0.004167 × 10 = I_load × 0.04167
ADC 读数: Vadc = Vsense (ADC 输入范围 0~3.3V)
```

#### 5.1.2 电流环开环传递函数

```
被控对象 (从占空比到电流):
  Gp(s) = gm_total × (3.3V × 0.95) / (1 + s/ωp)
  其中 ωp ≈ 1/(R_load × C_load) — 负载极点
  在 CC 模式下，负载可视为短路 (低阻抗)，ωp 较高

电流检测:
  H(s) = R_sense × A_i_sense = 0.04167

环路增益:
  L(s) = Gc(s) × Gp(s) × H(s)
```

#### 5.1.3 当前 PI 参数

| 参数 | 值 | 单位 |
|---|-----|---|
| Kp | 0.5 | — |
| Ki | 10.0 | — |
| Kd | 0.001 | — |
| dt | 0.001163 | s |

**连续域等效**:
```
Ki_continuous = Ki × dt = 10.0 × 0.001163 = 0.01163
Ti = Kp / Ki_continuous = 0.5 / 0.01163 ≈ 43 s
```

**穿越频率估算**:
```
在零点频率 fz = 1/(2π×Ti) ≈ 0.0037 Hz 之后，
增益以 -20 dB/dec 滚降。
假设电流环闭环带宽 ≈ 30~50 Hz (受 860 Hz 采样率限制)
```

> **注意**: 以上参数为初始值，需通过仿真 (pid_sim.py) 和实际测试进一步调优。

### 5.2 电压环参数推导

#### 5.2.1 被控对象模型

**电压检测分压器**: 1/13.2
```
Vadc = Vin × (1/13.2)
ADC 满量程 3.3V 对应输入电压: 3.3 × 13.2 = 43.56V (使用分压)
实际输入可达 150V，需附加衰减或 ADC 支持更高范围
```

**电压环被控对象 = 电流环闭环**:
```
电压环输出 → 电流给定 → 电流环闭环 → 负载电流 → 负载电容充电 → 电压
```

#### 5.2.2 当前 PI 参数

| 参数 | 值 | 单位 |
|---|-----|---|
| Kp | 0.2 | — |
| Ki | 2.0 | — |
| Kd | 0.0 | — |
| 输出限幅 | 0 ~ 110.0 | A |

**连续域等效**:
```
Ki_continuous = Ki × dt = 2.0 × 0.001163 = 0.002326
Ti = Kp / Ki_continuous = 0.2 / 0.002326 ≈ 86 s
```

电压环带宽应远低于电流环 (约 1/5 ~ 1/10)。

### 5.3 调优策略

建议调试流程:
1. **电流环调试**: 断开外环，纯 CC 模式，阶跃响应测试
2. **电压环调试**: CV 模式下，逐步增加 Kp 直到出现振铃，然后回调 50%
3. **功率环调试**: CW 模式下，采用与电压环类似的 PI 参数 (预期 Kp ≈ 0.1, Ki ≈ 1.0)

---

## 6. 模式切换逻辑

### 6.1 模式类型

| 模式 | 控制策略 | 说明 |
|---|---|---|
| CC | 电流 PID → Duty | 直接控制电流 |
| CV | 电压 PID → 电流 PID → Duty | 级联: 外环电压 → 内环电流 |
| CR | 电阻 PID → 电流 PID → Duty | 级联: 外环电阻 → 内环电流 |
| CW | 功率 PID → 电流 PID → Duty | 级联: 外环功率 → 内环电流 |

### 6.2 模式切换时序

```
触发条件: UART 命令 (CMD_SET_MODE)

流程:
1. 停止当前模式 (电流环/电压环 → duty = 0)
2. 重置当前模式 PID 状态 (pid_reset)
3. 配置新模式 PID 参数
4. 启用软启动 (soft-start, ~100 次迭代 = 116 ms)
5. 标记切换完成

保护: 切换期间禁止输出 ON 到 OFF 跳变
```

### 6.3 CC↔CV 交叉切换 (Crossover)

当同时设置 CC 和 CV 限制时:
```
if measured_v > cv_setpoint AND mode == CC:
    # 自动切换到 CV 模式
    modes_switch(MODE_CV)
elif measured_a > cc_setpoint AND mode == CV:
    # 自动切换到 CC 模式
    modes_switch(MODE_CC)
```

> **当前暂未实现**: 需要增加自动交叉逻辑 (auto-range crossover)。

### 6.4 瞬态响应规格

| 参数 | 目标 | 测量条件 |
|---|---|---|
| 上升时间 (tr) | < 1 ms | CC 0→30A, 电阻负载 |
| 过冲 (Overshoot) | < 5% | CC 0→30A, 电阻负载 |
| 稳定时间 (ts ±2%) | < 5 ms | CC 0→30A, 电阻负载 |
| CV 稳定时间 | < 20 ms | CV 0→12V, 电池负载模拟 |

---

## 7. 保护集成

### 7.1 硬件保护 (CMPSS)

C2000 F28E12x 的 CMPSS 子系统提供纳秒级硬件比较器：

| 通道 | 正输入 | 负输入 (DAC) | 触发阈值 | 动作 |
|---|---|---|---|---|
| CMPSS1 | 电压检测 | DAC1 | OVP: 150V | PWM TZ1 trip |
| CMPSS2 | 电流检测 | DAC2 | OCP: 110A | PWM TZ2 trip |
| CMPSS3 | PSU 监控 | DAC3 | UVLO: 10.8V | 系统关断 |

**硬件保护路径**:
```
               CMPSS
Vin ─┬─► ADC ──► +│
     │           │ │──► TZ (Trip Zone) ──► HRPWM Force Hi-Z
     └─► 分压 ───► -│ (DAC 阈值)
```

**安全特性**:
- TZ 触发后自动闭锁 (latch)，需手动清除故障标志
- 故障清除后通过 CMPSS 数字滤波消抖

### 7.2 软件保护

由 `protection_task` 在 1 kHz 下执行：

| 保护项 | 阈值 | 滞后 | 动作 |
|---|---|---|---|
| OVP | 150V | 5V | PWM shutdown + 故障标志 |
| OCP | 110A | 2A | PWM shutdown + 故障标志 |
| OPP | 1050W | 20W | PWM shutdown 或功率折返 |
| OTP | 90°C | 10°C | 75°C 折返 → 90°C 关断 |
| 通信超时 | 500ms | — | 保持当前设置 + 警告 LED |

### 7.3 软件限幅 (在 PID 输出端)

```
电流环: duty = clamp(duty, 0.0, 0.95)
电压环: I_demand = clamp(I_demand, 0.0, 110.0)
CC 限幅: soft_start_target = min(setpoint, 110.0)
CV 限幅: target_voltage = min(setpoint, 150.0)
```

---

## 8. 校准策略

### 8.1 校准数据结构

```c
typedef struct {
    float v_offset;     // 电压 ADC 偏置 (V)
    float v_gain;       // 电压 ADC 增益 (V/ADC_count)
    float i_offset;     // 电流 ADC 偏置 (A)
    float i_gain;       // 电流 ADC 增益 (A/ADC_count)
    uint8_t cal_valid;  // 0 = 无效, 1 = 有效
    uint32_t cal_date;  // Unix 时间戳
} el1000_calibration_t;
```

### 8.2 校准流程

#### 电压校准
```
1. 输入已知电压 V1 (如 10V)，记录 ADC 读数 ADC1
2. 输入已知电压 V2 (如 100V)，记录 ADC 读数 ADC2
3. 计算:
   v_gain = (V2 - V1) / (ADC2 - ADC1)
   v_offset = V1 - v_gain × ADC1
```

#### 电流校准
```
1. 设置负载电流 I1 (如 1A)，记录 ADC 读数 ADC1
2. 设置负载电流 I2 (如 50A)，记录 ADC 读数 ADC2
3. 计算:
   i_gain = (I2 - I1) / (ADC2 - ADC1)
   i_offset = I1 - i_gain × ADC1
```

### 8.3 校准模式

通过 UART 命令 `CMD_CAL_MODE` 进入校准模式：
1. 系统进入 STATUS_CAL
2. 禁用保护阈值 (仅硬件 CMPSS 保持)
3. 使用外部精密万用表 (6.5 位) 作为参考
4. 每个通道校准后写入 EEPROM
5. 校准数据上电时校验，无效则使用默认值

### 8.4 精度预算

| 参数 | 目标精度 | 主要误差源 |
|---|---|---|
| 电压测量 | ±0.1% FS | 分压电阻精度 (±1%) → 校准后 |
| 电流测量 | ±0.2% FS | RS6332 Vos (0.8mV), 感测电阻 (±1%) |
| 设定分辨率 | 0.01A / 0.01V | HRPWM 15.2bit + 校准后 |

---

## 9. 待办事项 (TODO)

- [ ] 通过 pid_sim.py 仿真验证 PI 参数
- [ ] 硬件实测后调整 Kp/Ki
- [ ] 实现 CR 模式外环 PID
- [ ] 实现 CW 模式外环 PID
- [ ] 实现 CC↔CV 自动交叉
- [ ] 实现增益调度 (Gain Scheduling) — 根据工作点切换 PI 参数
- [ ] 实现前馈补偿 (Feed-Forward) — 加快瞬态响应
- [ ] 实现继电器反馈自整定 (Relay Feedback Auto-Tune)
- [ ] CMPSS 硬件阈值可通过 UART 配置
- [ ] 故障日志存入 EEPROM
- [ ] 功率折返 (Power Foldback) 的温度曲线

---

## 附录 A: 电流环 Simulink 模型参数

```
采样时间: Ts = 1/860 ≈ 1.163e-3 s
PI 控制器: Kp = 0.5, Ki = 10.0 (离散域, Ki × Ts = 0.01163)
感测增益: H = 0.04167 V/A
MOSFET gm: 240 S
PWM 增益: 3.135 (3.3V × 0.95)
负载极点: f_p = 1/(2π × R_load × C_load)
```

## 附录 B: PI 参数速查表

| 模式 | Kp | Ki | Kd | 输出范围 | 说明 |
|---|----|----|-----|---|---|
| CC | 0.5 | 10.0 | 0.001 | 0~0.95 | 电流内环 |
| CV | 0.2 | 2.0 | 0.0 | 0~110A | 电压外环 |
| CR | TBD | TBD | 0.0 | 0~110A | 待调试 |
| CW | TBD | TBD | 0.0 | 0~110A | 待调试 |

---

*文档结束 — SYS-CTRL-001 v0.1*

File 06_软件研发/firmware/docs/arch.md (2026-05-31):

# EL-1000 Firmware Architecture

## 1. System Overview

```
┌──────────────────────────────────────────────────┐
│                   ESP32-S3                        │
│  ┌──────────┐  ┌───────────┐  ┌───────────────┐  │
│  │ WebServer │  │ WebSocket │  │   LVGL UI     │  │
│  │ (REST)    │  │ (realtime)│  │   (4.3" LCD)  │  │
│  └─────┬────┘  └─────┬─────┘  └───────┬───────┘  │
│        │              │                │          │
│  ┌─────┴──────────────┴────────────────┴───────┐  │
│  │            App Message Queue                 │  │
│  └────────────────────┬────────────────────────┘  │
│                       │ UART (921600 baud)         │
├───────────────────────┼──────────────────────────┤ │
│                 ┌─────┴──────┐                     │
│                 │ UART ISR   │                     │
│                 │ (SCI-A)    │                     │
│                 └─────┬──────┘                     │
│                       │                            │
│  ┌────────────────────┼────────────────────────┐  │
│  │            C2000 F28E12x                    │  │
│  │  ┌──────────┐  ┌──────────┐  ┌──────────┐  │  │
│  │  │ PID Task │  │Protection│  │  Comm    │  │  │
│  │  │ @860Hz   │  │ @1ms     │  │  Task    │  │  │
│  │  └────┬─────┘  └────┬─────┘  └────┬─────┘  │  │
│  │       │              │             │         │  │
│  │  ┌────┴──────────────┴─────────────┴──────┐  │  │
│  │  │         FreeRTOS Scheduler             │  │  │
│  │  └───────────────────┬────────────────────┘  │  │
│  │                      │                        │  │
│  │  ┌───────────────────┴────────────────────┐  │  │
│  │  │   HAL/Driver Layer (HRPWM, ADC, CMPSS) │  │  │
│  │  └────────────────────────────────────────┘  │  │
│  └──────────────────────────────────────────────┘  │
└──────────────────────────────────────────────────┘
```

## 2. Task Map (C2000 — FreeRTOS)

| Task | Priority | Period | Stack | Description |
|---|---|---|---|---|
| `pid_task` | 5 (highest) | 1.16 ms (860 Hz) | 512 | PID computation, DAC/HRPWM update |
| `protection_task` | 4 | 1 ms | 256 | OVP, OCP, OTP, OPP checks |
| `comm_task` | 3 | 10 ms (poll) | 512 | UART framing, command dispatch |
| `housekeeping_task` | 2 | 100 ms | 256 | ADC avg, status LED, debug log |
| `idle_task` | 0 | — | 128 | WFI sleep |

### ISR priorities
- HRPWM update (ePWM1): ISR @25 kHz — highest
- ADC EOC (end-of-conversion): ISR @860 Hz
- UART RX (SCI-A): ISR on byte received

## 3. Task Map (ESP32 — FreeRTOS)

| Task | Core | Priority | Description |
|---|---|---|---|
| `uart_rx` | 0 | 10 | UART byte reception & framing |
| `ws_server` | 1 | 5 | WebSocket broadcast @10 Hz |
| `http_server` | 1 | 4 | REST API request handler |
| `display_tick` | 1 | 3 | LVGL timer tick & refresh @30 Hz |
| `encoder_scan` | 0 | 2 | Rotary encoder debounce & events |
| `wifi_mgr` | 0 | 1 | Wi-Fi reconnect, AP scan |

## 4. Data Flow

### Control path (fast, C2000 only)
```
ADC (13ch) → PID task → Duty cycle → HRPWM → MOSFET gate
       ↑                     |
       └── Protection task ──┘  (trips output on fault)
```

### Telemetry path (slow, C2000 → ESP32)
```
Housekeeping task → Ring buffer → Comm task → UART → ESP32
                                                       ↓
                                             WebSocket / LVGL / REST
```

### Command path (ESP32 → C2000)
```
UI / API / WebSocket → Comm task (ESP32) → UART → Comm task (C2000)
                                                       ↓
                                              Mode switch / Setpoint
```

## 5. Protection Strategy

Protection is **hardware-backed** with CMPSS comparators on the C2000 for
the fastest trip times, and **software-monitored** by the protection task
for configurable thresholds and hysteresis.

| Protection | Hardware | Software | Action |
|---|---|---|---|
| OVP | CMPSS1 (V > threshold) | ADC check @1ms | PWM trip + GPIO shutdown |
| OCP | CMPSS2 (I > threshold) | ADC check @1ms | PWM trip + GPIO shutdown |
| OTP | — | NTC ADC @100ms | Foldback then shutdown |
| OPP | — | V*I compute @1ms | Foldback then shutdown |
| Reverse V | External comparator | — | MOSFET body diode blocks |

## 6. HRPWM Configuration

- **PWM frequency**: 25 kHz (Tperiod = 40 µs)
- **HRPWM resolution**: ~150 ps (MEP step)
- **Dead-band**: 200 ns (complementary PWM for synchronous rectification)
- **Trip zone**: TZ1 (CMPSS1), TZ2 (CMPSS2), TZ3 (software force)

## 7. UART Protocol

Binary frame-based protocol (see `common/protocol.h`). Frame:
```
[SYNC0: 0xAA] [SYNC1: 0x55] [LEN] [CMD] [PAYLOAD..] [CRC16-LO] [CRC16-HI]
```

ESP32 is bus master — initiates all transactions. C2000 responds within 1 ms.

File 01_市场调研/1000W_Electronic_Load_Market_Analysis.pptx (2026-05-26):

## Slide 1

1000W DC Electronic Load

Market Analysis & Product Opportunity Report

May 2026 | Confidential

$4.0B

2026 Global
Market Size

7.5%

Annual
Growth Rate

17%

1kW Segment
Share

$800-$2k

Target Price
Range

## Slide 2

Global DC Electronic Load Market Size & Growth

Key Findings

Market Size (2025): $3.75B → Growing to $5.38B by 2030
CAGR: 6-11% depending on report source
DC loads dominate; AC+DC combined market tops $4.7B
1000W sits at the sweet spot between benchtop and modular systems
Asia-Pacific accounts for ~48% of global revenue

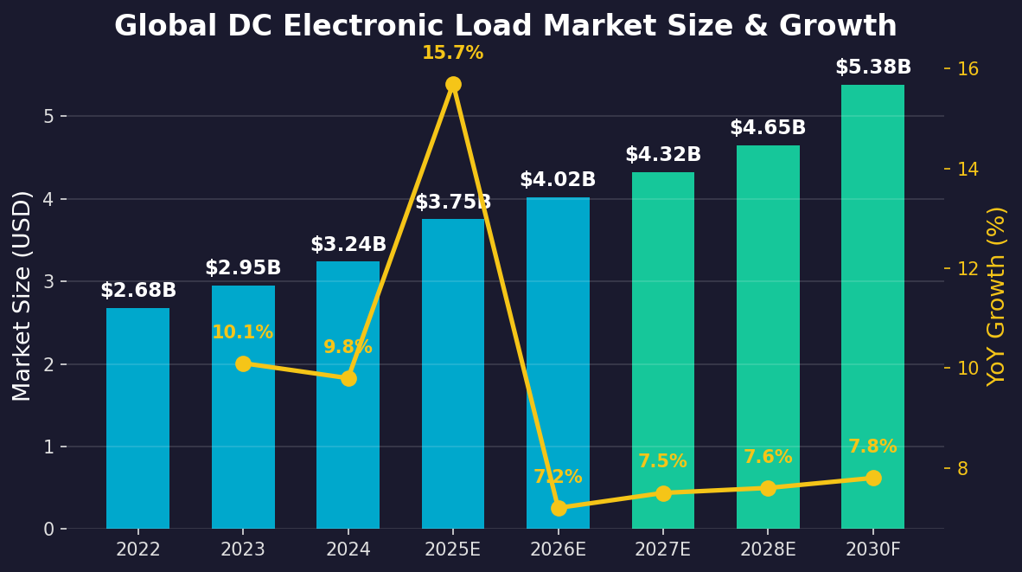
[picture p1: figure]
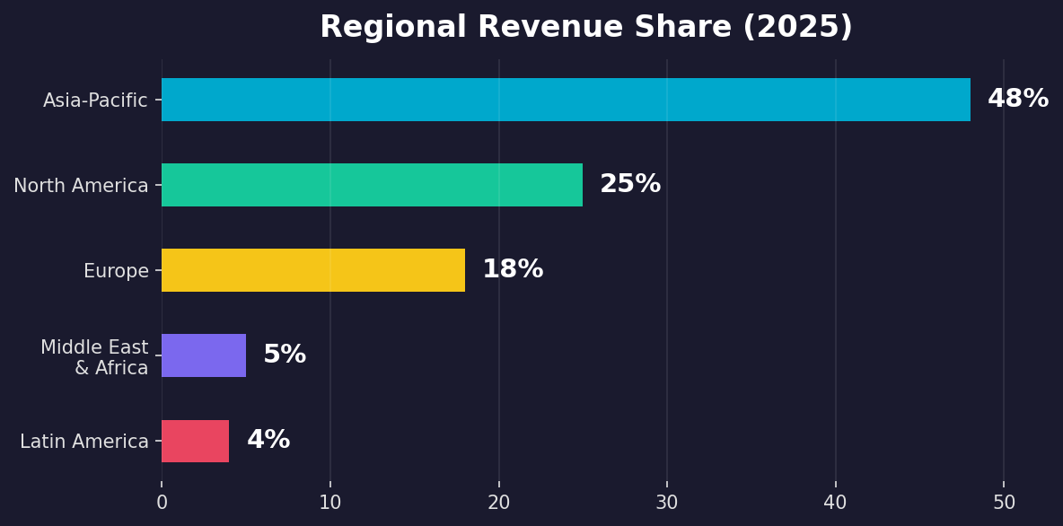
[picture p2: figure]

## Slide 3

Market Segmentation: By Power & Application

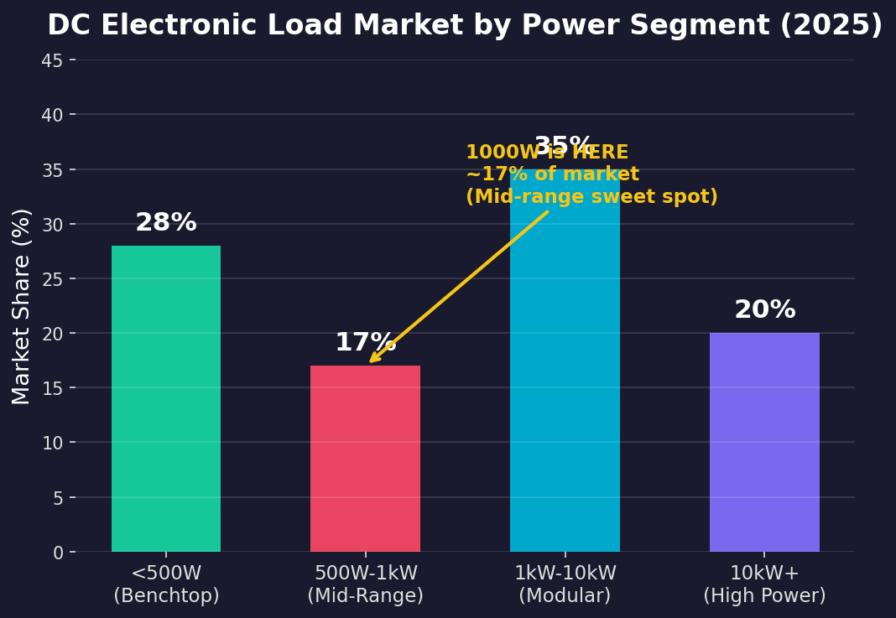
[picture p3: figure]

1000W Segment Characteristics
Falls into 1kW-10kW "modular" segment (35% share)
Also overlaps with mid-range 500W-1kW (17% share)
Ideal for server PSU, EV module, solar inverter testing
3-5x more applications than 500W-class

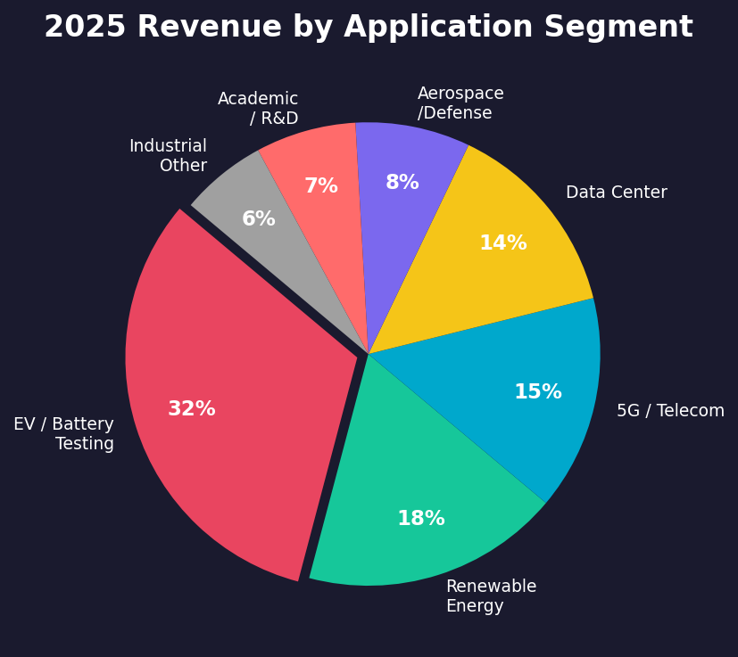
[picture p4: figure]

Why 1000W > 500W
Addressable market ~3x larger than 500W
Fewer DIY competitors (complexity jumps at 1kW+)
Higher ASP = better margins at same volume
Professional users have bigger budgets

Top Applications for 1000W Loads
EV battery module testing (up to 96V / 30A)
Server PSU validation (1kW ATX / redundant PSU)
Solar micro-inverter & charge controller testing
DC-DC converter efficiency measurement

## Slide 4

Competitive Landscape: 1000W-Class DC Electronic Loads

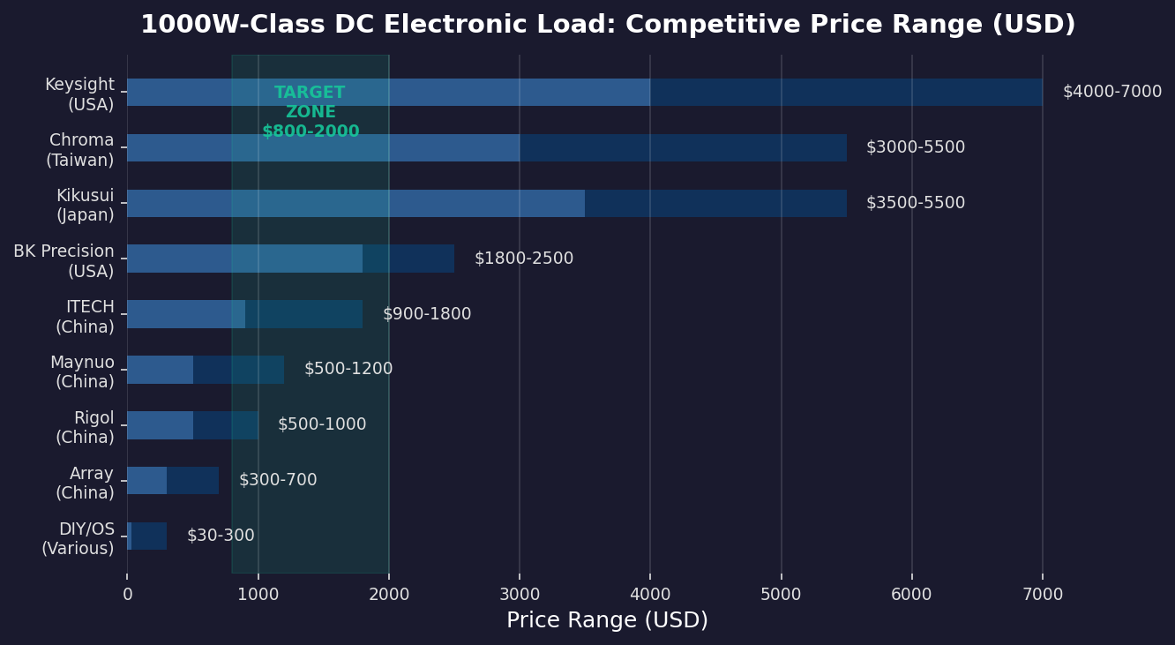
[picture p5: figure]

Tier 1: Premium ($3,000-7,000)
Keysight, Chroma, Kikusui
Accuracy <0.1%, extensive protocol support
Target: enterprise, defense, aerospace
Key weakness: terrible software UX, slow innovation

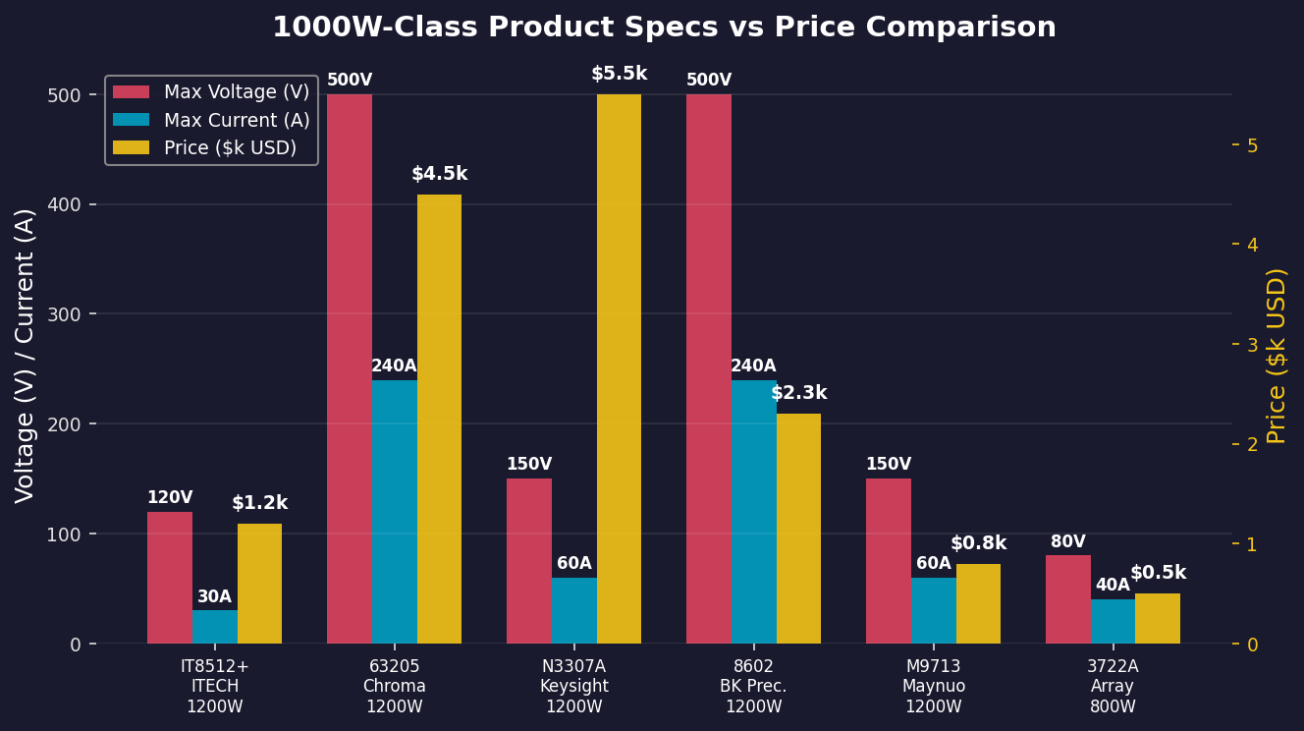
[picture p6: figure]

Tier 3 & DIY ($30-1,200)
Maynuo, Array, unknown Taobao brands, Arduino+MOSFET
Low accuracy (>0.5%), minimal protection
Target: makers, students, budget-constrained labs
Open-source community wants a serious 1kW design

Tier 2: Mid-Market ($800-2,500)
ITECH (CN), BK Precision (US), Rigol (CN)
Good accuracy (0.1-0.5%), decent software
Target: R&D labs, testing houses
ITECH dominates China / BK Precision dominates US

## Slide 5

Growth Drivers & Technology Trends

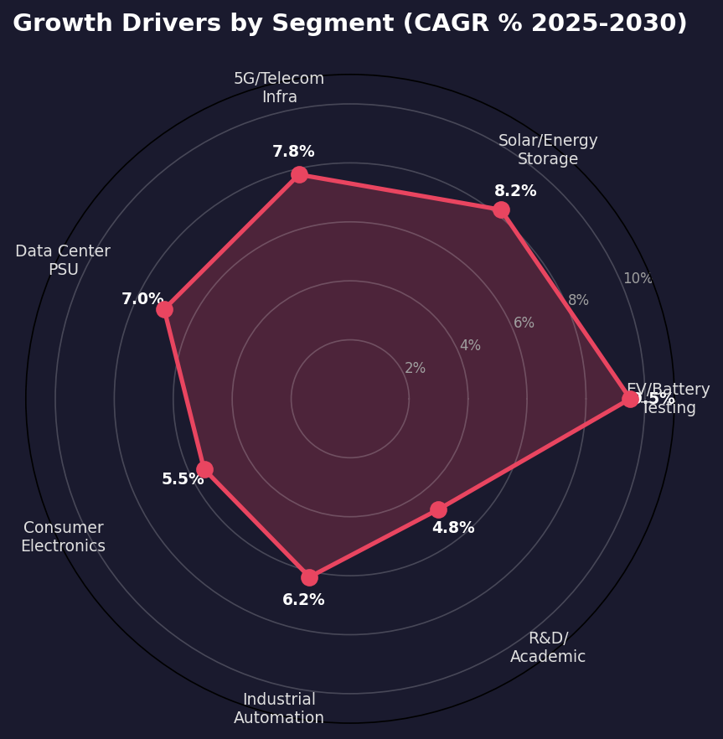
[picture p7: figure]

Market Growth Catalysts

EV Battery Testing (CAGR 9.5%)
Global EV penetration rising from 18% to 35%+
Battery cell, module, and pack-level testing all need DC loads
Charging station compliance testing mandates grow
Solar + Energy Storage (CAGR 8.2%)
Residential storage boom: 100 GWh new installs expected by 2030
Micro-inverter and hybrid inverter testing requires 1kW range
5G Infrastructure (CAGR 7.8%)
5G base stations require 3x more power testing than 4G
Small-cell deployment driving volume demand
Tech Trend: Smart + Connected Test Equipment
Wi-Fi / BLE / LAN remote control becoming expected
Cloud data logging and AI-driven test automation emerging
Software-defined test instruments - update via firmware

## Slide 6

Target User Profile & Addressable Market

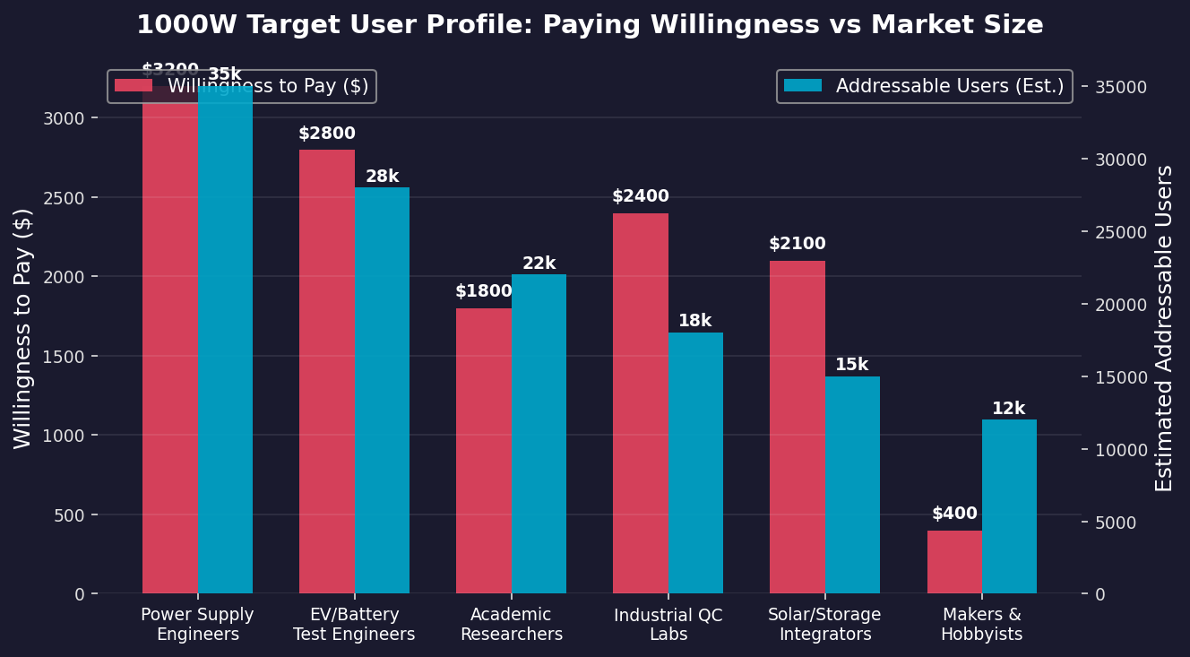
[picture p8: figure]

Primary: Power Supply Engineers (35k users)
Need: accurate, programmable, affordable 1kW load for PSU validation
Pain: Keysight budget rejected by management, ITECH not trusted
WTP: $1,500-3,500 | Total SAM: $80-120M

Secondary: EV/Battery Engineers (28k users)
Need: CC/CV/CP modes, battery discharge curves, data logging
Pain: Chroma too expensive for startup teams
WTP: $1,800-4,000 | Total SAM: $65-90M

Tertiary: Academic & Maker (34k users)
Need: affordable multi-channel loads for student labs
Pain: current options either junk or unaffordable
WTP: $400-1,500 | Total SAM: $20-35M

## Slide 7

Opportunity Gap Analysis: Where to Compete

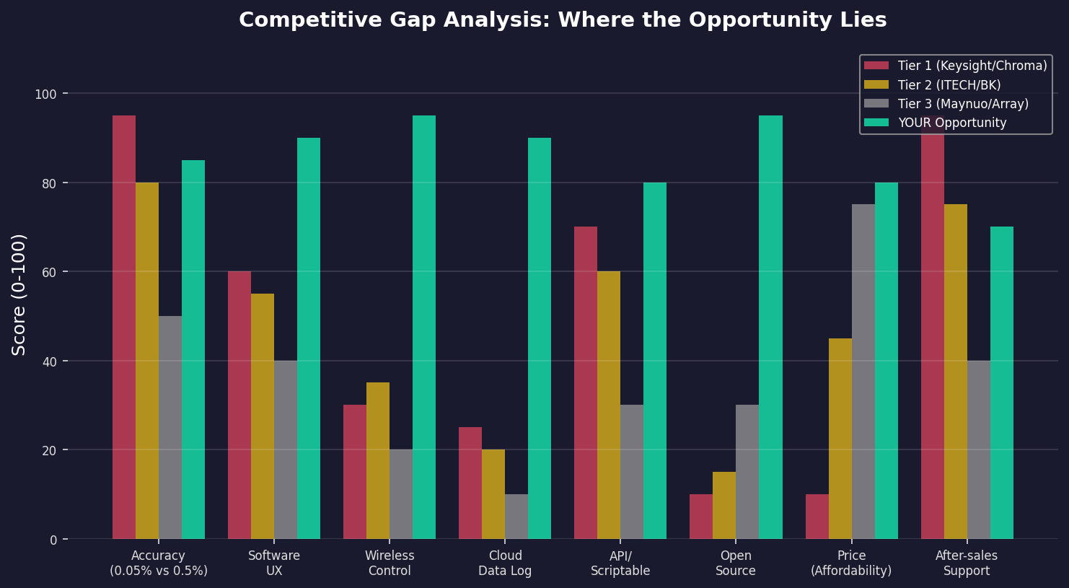
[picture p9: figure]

Conclusion: The biggest competitive window is in "Software UX + Connectivity + Price" — not trying to beat Keysight on raw accuracy.

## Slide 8

Recommended Product Positioning

Positioning Statement
A 1000W programmable DC electronic load that delivers ITECH-grade accuracy at Maynuo-grade pricing,
with modern software (web UI, Wi-Fi, API-first) that makes Keysight s look 20 years old.
Target retail price: ¥3,999-5,999 (~$550-830) — undercutting ITECH by 30-40% with better software.

Hardware Spec Target
Power: 1000W continuous (1200W peak)
Voltage: 0-150V DC
Current: 0-60A DC
Accuracy: 0.1% ± 0.05% FS (on par with ITECH)
Modes: CC / CV / CP / CR + Battery Test
Protection: OTP / OVP / OCP / OPP / Reverse Polarity
Interface: USB-C + Wi-Fi 6 + BLE 5.0

Software Differentiators
Web-based control panel (no install needed)
REST API + Python SDK for automation
Cloud data logging & real-time dashboards
Firmware OTA updates via Wi-Fi
Multi-device synchronization (parallel loads)
Export data to CSV / JSON / Grafana
iOS / Android companion app

Go-to-Market Strategy
Phase 1: Open-source hardware design to build community
Phase 2: Crowdfunding (Kickstarter / zeczc) pre-sales
Phase 3: Direct e-commerce + AliExpress / Amazon
Phase 4: Distributor partnerships for B2B channels
Target: ship 500 units in first 12 months
Break-even at ~200 units at $699 ASP
Community = free QA, content, and word-of-mouth

Product Architecture Overview
MCU (STM32H7 / ESP32-S3) + FPGA (gate driver PWM) → MOSFET bank (8x IRFP250N parallel) → Active cooling
Isolated ADC (ADS1115) + shunt resistors → 16-bit current sensing → PID loop @ 10kHz → 0.1% accuracy target
Wi-Fi/BLE (ESP32-S3) + Web Server → REST API → Optional Cloud Sync → Companion App + CLI Tool

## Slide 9

5-Year Financial Projection (Illustrative)

Year 1

Year 2

Year 3

Year 4

Year 5

Units Sold

200

500

1,200

2,500

5,000

Revenue (@$700 ASP)

$140K

$350K

$720K

$1.5M

$3.0M

COGS (@55% target)

$84K

$193K

$396K

$825K

$1.65M

Gross Margin (45%)

$56K

$157K

$324K

$675K

$1.35M

Investment Required
Hardware R&D (prototyping, PCB, BOM): $15,000-25,000
Software development (FW + web + app): $10,000-15,000
Certification (CE/FCC/3C): $5,000-10,000
Initial production run (200 units): $40,000-60,000
Total seed capital needed: ~$70,000-110,000
Break-even: ~200 units (within 12-18 months)

ROI & Exit Potential
Year 3 EBITDA: ~$250K (net after OpEx of ~$75K)
Valuation at Y3: 6-8x EBITDA = $1.5-2M (conservative)
Potential acquirers: ITECH, Rigol, Siglent (looking for SW talent)
Alternative: stay bootstrapped, 5-year cumulative margin >$2.5M
Kickstarter target: $50K (500 backers × $100 avg pledge)
China domestic market alone can support 5,000+ units/yr

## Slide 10

Key Risks & Mitigations

1. Hardware Accuracy Claims

Risk: failing to deliver 0.1% accuracy kills credibility. Mitigation: partner with calibration lab during R&D; publish third-party accuracy reports; be transparent about limitations.

2. Thermal Management at 1kW

Risk: 1000W of heat dissipation is non-trivial. Mitigation: use actively cooled MOSFET bank with thermal feedback; over-engineer heatsink; auto-derating above 85C ambient.

3. Supply Chain / BOM Cost

Risk: component costs make $699 ASP impossible. Mitigation: use commodity MOSFETs (IRFP250N) in parallel; ESP32-S3 is $3; avoid exotic parts; design for manufacturability.

4. ITECH/Maynuo Price War

Risk: incumbents lower prices to crush you. Mitigation: compete on software & community, not just price; open-source creates stickiness; target niches they ignore (makers, startups).

5. Safety & Liability

Risk: 1kW DC load is dangerous if misused. Mitigation: multiple redundant protections (HW + SW); CE/FCC/3C certification; clear warning labels; liability insurance; open-source = shared responsibility.

6. Copycats (especially in China)

Risk: design gets cloned within 6 months. Mitigation: open-source IS the strategy — build the brand and community; clones validate the market; keep moving faster; software moat.

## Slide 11

Next Steps: From Analysis to Action

Phase 1: Deep Dive (Weeks 1-2)

Tear down 3 competitor products (IT8512+, M9713, 8602)
Benchmark accuracy, ripple, thermal performance
Interview 10 target users (engineers on Taobao, Zhihu, EEVblog)

Phase 2: Architecture Design (Weeks 3-4)

Select MCU + MOSFET topology; run SPICE simulation
Draft schematics, BOM cost estimate, PCB outline
Write firmware architecture spec + web UI wireframes

Phase 3: Prototype (Weeks 5-8)

Build 2 prototype units; test to destruction
Iterate on thermal design; validate accuracy claims
Publish open-source repo with design files and docs

Phase 4: Crowdfunding Prep (Weeks 9-12)

Produce demo video with real-world testing scenarios
Set up supply chain for 200-unit production run
Launch Kickstarter / zeczc campaign

Questions? Next discussion: Product spec definition & architecture design

Thanks for reviewing. Let s build something that engineers actually want to use.

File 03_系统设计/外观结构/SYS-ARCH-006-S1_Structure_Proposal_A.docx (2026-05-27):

# SYS-ARCH-006: S1 Structure Scheme - Heatsink as Central Spine

Date: 2026-05-27 | Related document: SYS-ARCH-006 v0.1 | Proposal: A - Heatsink as structural core

# Structure Concept Summary

The heatsink (350x150x50mm aluminum extrusion) serves as the central structural spine of the enclosure. Front and rear panels bolt directly to the heatsink ends. PCBs mount on standoffs attached to the heatsink flat face. SPCC steel enclosure panels (top, bottom, sides) attach to the heatsink flange edges, forming a "heatsink spine + wrapped shell" sandwich structure.

Rationale: Heatsink (~2.5kg) is the heaviest single component. Using it as the structural element eliminates redundant frame weight. Critical given our <5kg target and 131W/L power density.

# Visual Diagrams

Refer to the embedded diagram below showing 4 views: structure exploded view, front panel layout, rear panel layout, and internal top view.

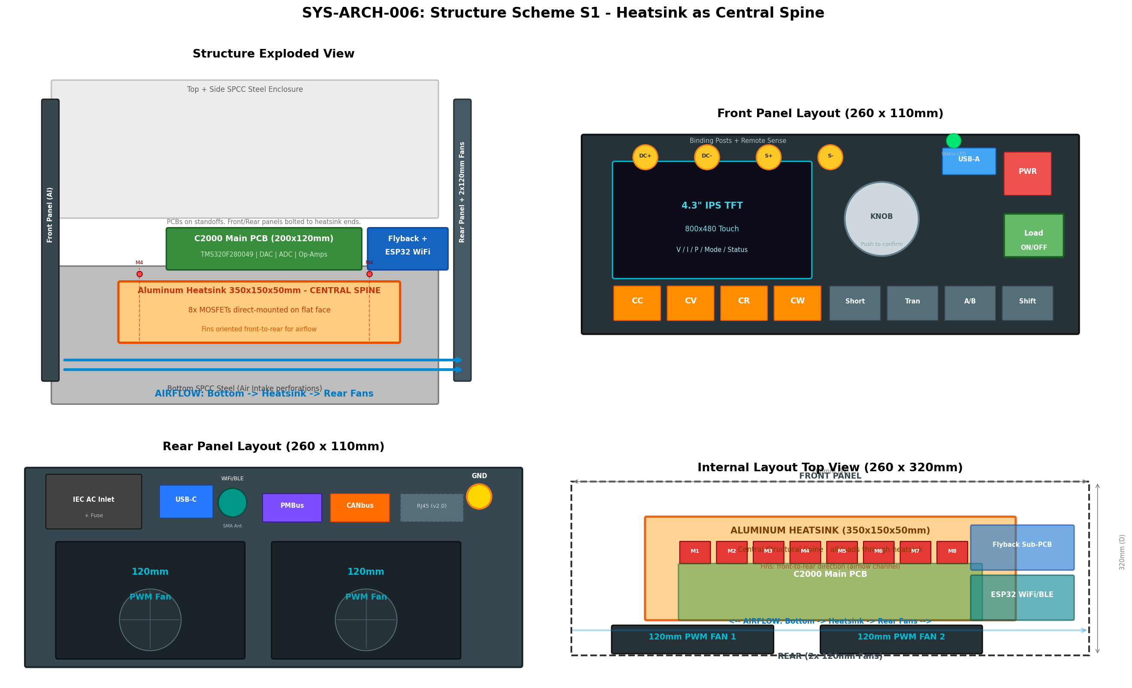
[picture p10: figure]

Figure 1: SYS-ARCH-006 S1 Structure Scheme - 4-View Diagram

## Key Dimensions Summary

Enclosure: W260 x D320 x H110mm (9.15L)

Heatsink: 350 x 150 x 50mm aluminum extrusion

Main PCB: 200 x 120mm (C2000 TMS320F280049)

Flyback sub-PCB: ~70 x 50mm

Fans: 2x 120mm PWM, rear exhaust

Airflow: Bottom intake -> heatsink fins -> rear fan exhaust

## Weight Estimation

Heatsink: ~2.5kg | Enclosure (SPCC): ~1.0kg | PCBs + components: ~0.5kg | Fans: ~0.3kg | Other (transformer, wiring, posts): ~0.7kg | TOTAL: ~5.0kg

Risk: Weight target (<5kg) is very tight. Recommend relaxing to 6-7kg if thermal/structural margin needed.

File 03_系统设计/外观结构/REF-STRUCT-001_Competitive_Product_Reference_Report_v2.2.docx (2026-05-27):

# 1200W 电子负载 - 同类产品外观结构参考报告

Doc: REF-STRUCT-001 | Date: 2026-05-27 | Version: v2.2

# Report Note

This report focuses on 1200W-class programmable DC electronic load products. Product images are sourced from official manufacturer websites and authorized distributor product pages.

# 1. 1200W Competitive Product Lineup

Brand | Model | Power | V/I | Form | Dims(mm) | Weight | Price
ITECH | IT8814B | 1200W | 500V/60A | Bench/3U | 440x530x176 | ~20kg | $1200-1800
ITECH | IT8812C | 1200W | 120V/120A | Bench/3U | 440x530x176 | ~20kg | $1200-1800
BK Precision | 8616 | 1200W | 500V/60A | Bench/3U | 440x510x155 | ~18kg | $2500-3000
BK Precision | 8614 | 1200W | 120V/120A | Bench/3U | 440x510x155 | ~18kg | $2500-3000
Maynuo | M9715 | 1800W | 150V/240A | Bench/3U | 428x454x207 | ~31kg | $1500-2000
Chroma | 63204E | 1200W | 1200V/160A | Rack/4U | 446x581x176 | ~22kg | $5000+
Array | 3710A | 1200W | 500V/60A | Bench/2.5U | 355x415x132 | ~12kg | $1200-1600
Faith | FT6800A | 1200W | Multi | Bench/3U | 440x525x178 | ~18kg | 8-15k RMB
GW Instek | PEL-3111 | 1050W | 150V/210A | Bench/3U | 430x500x155 | ~18kg | $1500-2200

>> Key: All 1200W competitors use 3U-4U large bench/rack form factors (19-46L, 12-31kg). Our design (260x320x110mm, 9.15L, <5kg) has 1/5 the volume and 1/4 the weight, with 4-8x the power density. This is the core design challenge.

# 2. Competitor Appearance Details

## 2.1 ITECH IT8814B (1200W / 500V / 60A)

ITECH IT8800 series. IT8814B is the 1200W model. Below: IT8811 photo (entire series shares same external design):

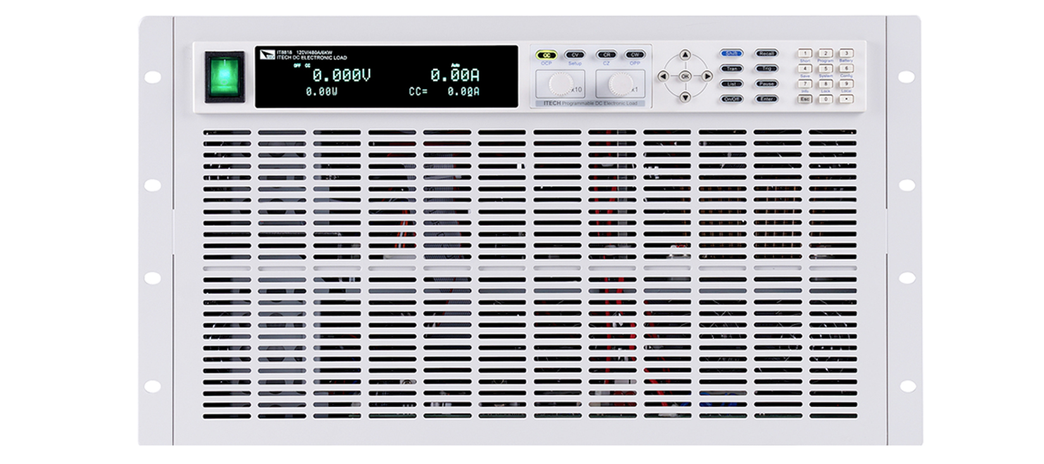
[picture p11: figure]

Fig 2.1: ITECH IT8800 Series Front Panel (Source: ITECH Official)

External Features:

- Standard bench instrument; folding carry handle + folding front support feet (panel tilt)

- Enclosure: cold-rolled steel stamping + powder coating (off-white); front: brushed Al + silkscreen. 440x530x176mm (41L), ~20kg

- Display: VFD (green), ~140x35mm, 2-line (large actual values + set values & status)

- Knob: right-mid, ~30mm Al knurled rotary encoder, push-to-confirm/edit

- Keys: Mode shortcuts (CC/CV/CR/CW) + Function (A/B,Short,Tran,Shift) + Numpad + Arrows

- Posts: bottom, 2 pairs large (DC+/DC-) + 1 pair Remote Sense (S+/S-)

- Switches: bottom-left rocker power, bottom-right Load On/Off (backlit LED)

Rear: IEC+fuse, USB-B, RS-232(DB9), GPIB(opt), multi-80mm fan exhaust, ground.

Internal: 3-board (front panel + main (MCU+DAC+ADC) + power (MOSFET bank + heatsink)). Large Al heatsink, rear fans, front-to-back airflow.

## 2.2 BK Precision 8616 (1200W / 500V / 60A)

BK 8616: North American mainstream 1200W. 8614/8616 share the same 3U chassis. 8614 = 120V/240A, 8616 = 500V/60A. Below: 8614 photo (same chassis as 8616):

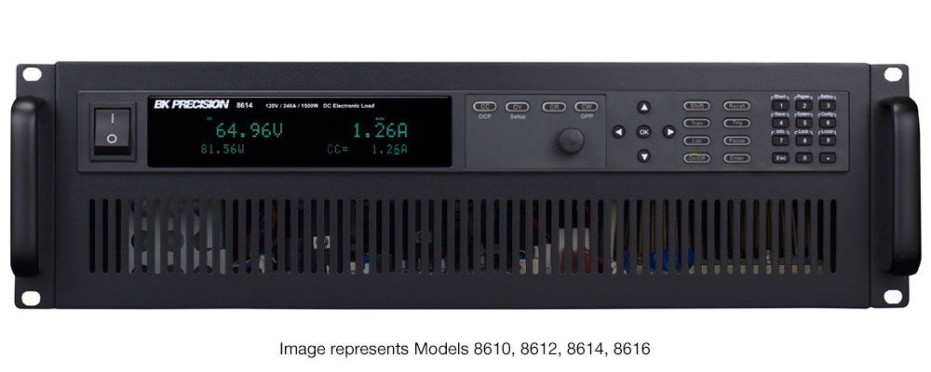
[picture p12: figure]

Fig 2.2-1: BK Precision 8614 Front Panel (same 3U chassis as 8616, Source: TTiD / BK Precision)

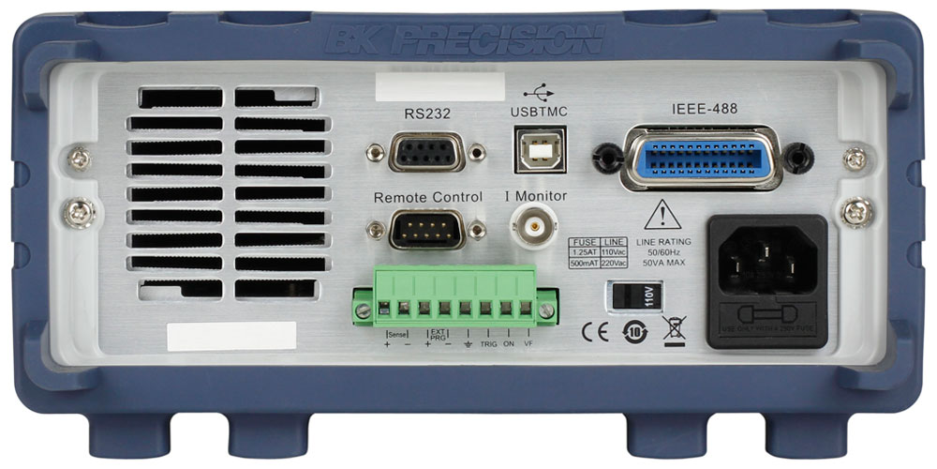
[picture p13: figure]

Fig 2.2-2: BK 8600 Series Rear Panel (8614/8616 3U model layout, Source: TTiD)

External Features:

- Benchtop 3U, dark gray enclosure + dark brushed Al front. 440x510x155mm (35L), ~18kg

- Display: VFD green high-bright, 4-line (best info hierarchy among competitors)

- Knob: right side, silver Al knurled (~28mm), push-to-confirm

- Keys: Mode (CC/CV/CR/CW/CR+CV) + Numpad + Arrows + Shift system

- Posts: bottom-left, 2 pairs heavy-duty (metal+insulation sleeve) + Remote Sense (S+/S-)

- Front USB Host (rare among competitors!), Load On/Off large button (green backlight)

Rear (Fig 2.2-2): IEC+fuse, USB-B, RS-232(DB9), GPIB(STANDARD), RJ45 LAN, 80mm fans x2, ground. BK has the most comprehensive interfaces. 3U models have binding posts on rear.

Internal: 3-layer (top I/O comm + middle main (DSP+DAC/ADC) + bottom power (Al heatsink+MOSFET array)). Ribbon/board-to-board, front-to-back airflow. Teardown issues: I/O FR4 ~1.2mm thin, encoder eccentric.

## 2.3 Maynuo M97 Series (M9715: 1800W)

Maynuo M97 series: mid-high-end Chinese electronic load, covers 150W-1800W. Consistent design from M9710 to M9715:

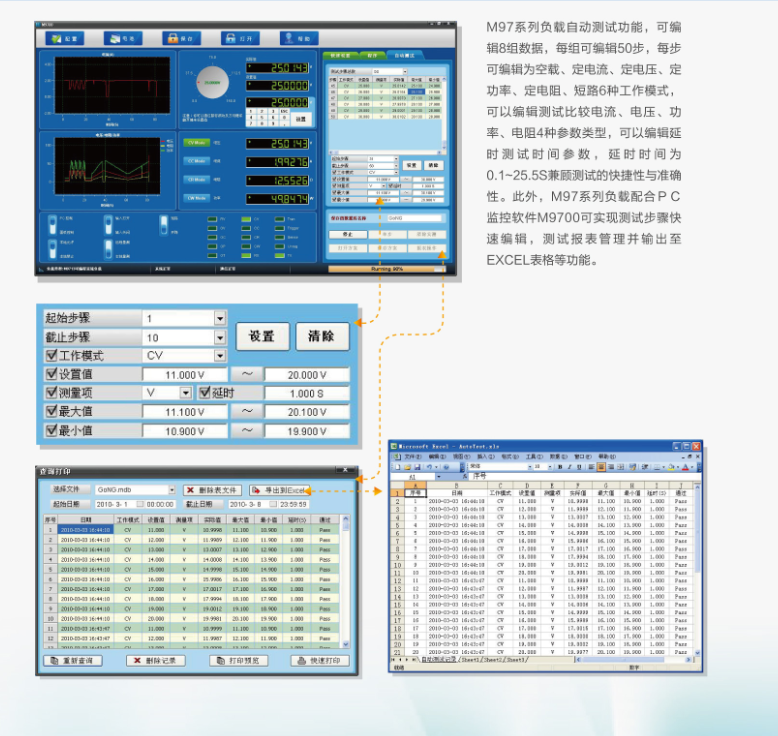
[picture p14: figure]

Fig 2.3-1: Maynuo M97 Series Front Panel (Source: Maynuo Official)

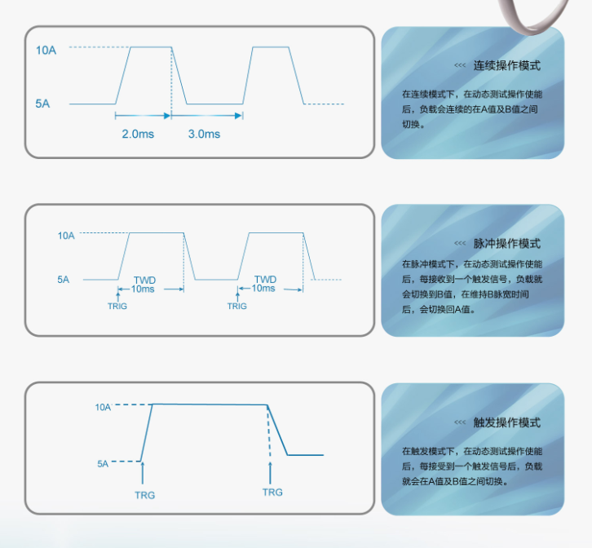
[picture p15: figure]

Fig 2.3-2: Maynuo M97 Front Detail (Source: Maynuo Official)

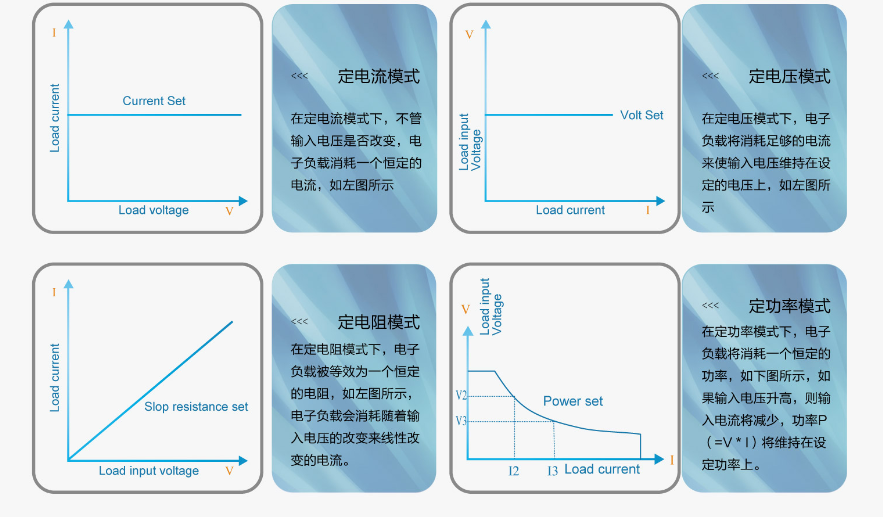
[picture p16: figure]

Fig 2.3-3: Maynuo M97 Front View (Source: Maynuo Official)

External Features:

- Benchtop 3U, silver-gray brushed Al front + light gray painted enclosure. 428x454x207mm (40L), ~31kg

- Display: large VFD (160x40mm, ~70% panel width), 4-line. Largest in class

- Knob: bottom-right, single (Al knurled) with LED ring showing status - strong brand identity

- Keys: Mode (CC/CV/CR/CW/CC+CV/CR+CV/Dynamic/Short) + Numpad + Arrows

- Posts: bottom, 2 pairs metal + Remote Sense. Compatible with banana plugs and fork terminals

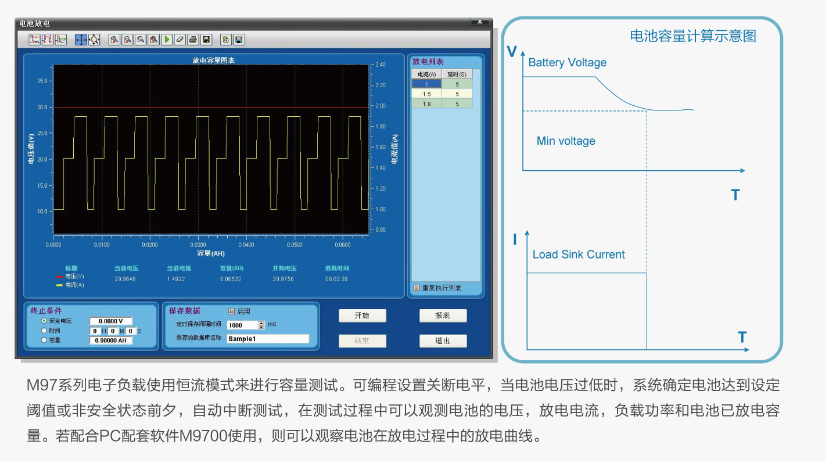
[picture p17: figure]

Fig 2.3-4: Maynuo M97 Rear Panel (Source: Maynuo Official)

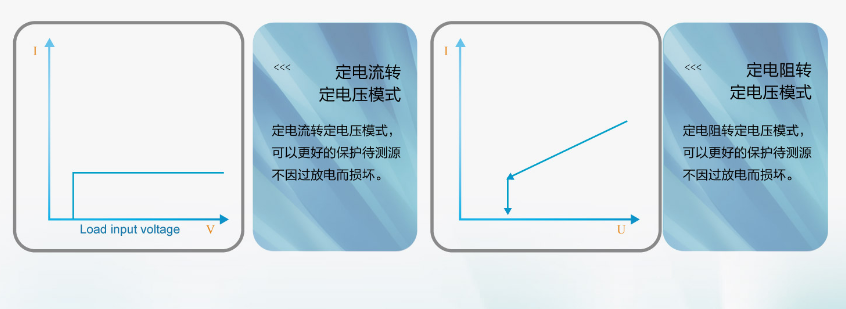
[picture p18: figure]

Fig 2.3-5: Maynuo M97 Detail (Source: Maynuo Official)

Rear: IEC+fuse, USB-B, RS-232(DB9), RS-485(terminal block - differentiating), dual 120mm fans, ground.

Internal highlight: SPLIT DUAL HEATSINK - two independent heatsinks each with MOSFET bank. Even thermal distribution, no hot spots. Measured ~43C at 230W (excellent). AD/BB/NXP/TI brand components. Modular connectors for easy service.

# 3. Internal Structure Comparison

Aspect | ITECH IT8814B | BK 8616 | Maynuo M9715 | Rigol DL3021 | Our Design
PCB arch | 3-board split | 3-board split | 3-board split | 3-board:dig+UI+pwr | C2000+flyback+ESP32
Interconnect | Ribbon cables | Ribbon+B2B | Modular connectors | PCIe(dig-UI)+ribbon | TBD
Controller | MCU | DSP | DSP/ARM | FPGA+ARM dual-core | C2000+ESP32
Power | MOSFET multi-parallel | MOSFET array | MOSFET dual-group | MOSFET bank | MOSFET parallel
Heatsink | Single large Al | Single large Al | Dual Al (split) | Large Al | Al ext 350x150x50
Fan | Multi x80mm rear | 2x80mm rear | 2x120mm rear | Single rear | 2x120mm rear
Airflow | Front-to-back | Front-to-back | Bottom-to-back | Front-to-back | Bottom->HS->rear
Enclosure | Steel+Al panel | Steel+Al panel | Steel+Al panel | Steel stamping | Al frame+SPCC

## Structure Design Rules

1. Control-Power board separation = industry iron law. High-current paths independent; control via ribbon/connectors.

2. All MOSFETs linear region; all heat via heatsink+fans. Power devices mounted directly on heatsink.

3. Airflow always front-to-back or bottom-to-back; fans always at rear. Never side exhaust.

4. Maynuo split dual heatsink = most noteworthy. Even thermal distribution, no hot spots. Optimal for high power.

5. Rigol PCIe interconnect = good signal integrity. Consider for high-speed board-to-board comm.

6. 100% sheet metal stamping+paint enclosure + brushed Al front. Zero competitors use full Al CNC.

7. 1200W competitors weigh 12-31kg (far > our <5kg), 4-8x volume. Thermal solutions cannot be directly copied.

# 4. Front Panel Design Comparison

## 4.1 Display

Brand | Tech | Color | Size | Lines | Feature
ITECH IT8814B | VFD | Green | 140x35mm | 2 | High brightness
BK 8616 | VFD | Green | 150x40mm | 4 | Best info hierarchy
Maynuo M9715 | VFD | Green | 160x40mm | 4 | Largest area (70% panel)
Chroma 63204E | OLED | Amber | ~120x30mm | Multi | Only OLED, best contrast
**OURS** | **IPS TFT** | **Color** | **4.3"** | **Touch GUI** | **Unique in class**

## 4.2 Knob

Brand | Qty | Type | Position | Dia | Push
ITECH | 1 | Rotary encoder | Right | ~30mm | Confirm/Edit
BK 8616 | 1 | Rotary encoder | Right | ~28mm | Confirm
Maynuo | 1 | Encoder+LED ring | Bottom-right | ~30mm | Confirm
Chroma | 1 | Rotary encoder | Right | ~32mm | Confirm
**OURS** | **1** | **Encoder w/ button** | **Right of LCD** | **TBD** | **Confirm**

## 4.3 Standard Front Panel Layout

All competitors follow the same proven ergonomic layout:

[Power Switch] [ D I S P L A Y ] [Vent]

[Mode: CC / CV / CR / CW] [K N O B]

[Func: Short/Tran/A/B/Shift] [Numpad 0-9]

[Arrow Keys] [Enter/Esc]

[Binding Posts +/-] [Remote Sense] [Load On/Off]

Frequency layers: High (mode/OnOff/short)=one-touch / Medium (params)=knob+numpad / Low (config)=menu

## 4.4 Binding Posts

Brand | Type | Qty | Sense | Rating | Compatibility
ITECH | Large metal posts | 2pr | 1pr S+/- | 60A | Banana+Fork+M6
BK 8616 | Heavy-duty (insulated) | 2pr | 1pr S+/- | 60A | Banana+Fork+M6
Maynuo | Large metal posts | 2pr | 1pr S+/- | 240A | Banana+Fork
Chroma | Bolt terminals | 1pr | Independent S+/- | 160A | Thick cable bolt

# 5. Rear Panel Interface Comparison

Interface | ITECH | BK 8616 | Maynuo | Chroma | Array | Ours
AC | IEC+fuse | IEC+fuse | IEC+fuse | IEC/Bus | IEC | IEC+fuse
USB Dev | USB-B | USB-B | USB-B | USB-B | USB | USB-C
USB Host | None | Front | None | None | None | USB-A (Front)
RS-232 | DB9 | DB9 | DB9 | DB9 | DB9 | None
GPIB | Optional | **Standard** | None | Optional | None | None
RS-485 | None | None | **Terminal** | Optional | None | None
LAN | None | **Standard** | None | Optional | None | Reserved
WiFi/BLE | None | None | None | None | None | **SMA Antenna**
PMBus | None | None | None | None | None | **2pin (unique)**
CANbus | None | None | None | None | None | **2pin (unique)**
Fan | Multi 80 | 2x80mm | 2x120mm | Multi 80 | 2x80mm | 2x120mm

>> Differentiator: PMBus + CANbus industrial fieldbus = unique in 1200W class. Competitors still use RS-232 + GPIB.

# 6. Power Density & Thermal Challenge

Product | Power | Vol(L) | Wt(kg) | W/L | W/kg
ITECH IT8814B | 1200W | 41.0 | ~20 | 29 | 60
BK 8616 | 1200W | 34.8 | ~18 | 34 | 67
Maynuo M9715 | 1800W | 40.2 | ~31 | 45 | 58
Chroma 63204E | 1200W | 45.6 | ~22 | 26 | 55
Array 3710A | 1200W | 19.4 | ~12 | 62 | 100
GW Instek PEL-3111 | 1050W | 33.3 | ~18 | 32 | 58
**OURS** | **1200W** | **9.15** | **<5** | **131** | **240**

!! Our power density (131 W/L) = 3.8x competitor avg, 2.1x most compact (Array).

Thermal implications: 1) Need 2-4x competitor efficiency 2) Noise > competitors (55-65dBA) 3) Fin density/fan selection critical 4) Array 3710A closest ref (62W/L) 5) Consider derating 6) Heatsink needs thermal sim

# 7. Teardown Lessons

# | Issue | Found In | Sev | Implication

1 | Poor ground: paint blocks path | Kunkin KP184 | H | Remove paint at contact points
2 | Bad thick-wire solder joints | Kunkin KP184 | H | Special process for power board
3 | Knob eccentric/not flush | BK 8600 | M | Precise shaft & cutout tolerance
4 | I/O board FR4 ~1.2mm | BK 8616 | M | PCB >=1.6mm, add stiffeners
5 | Flux residue not cleaned | BK 8600 | M | Wash or no-clean process
6 | Panel silkscreen/UI crude | Rigol DL3021 | M | Invest in professional design
7 | Post ID too small | Kunkin KP184 | H | Verify banana plug compatibility
8 | Buzzer poor quality | BK 8600 | L | Driver circuit + component test
9 | Full-load 55-65dBA noise | Multiple | M | Higher density = higher noise
10 | Inconsistent thermal protection | Multiple | H | Define OTP & derating strategy

# 8. Design Recommendations for SYS-ARCH-006

Form factor: All 1200W competitors = 3U-4U (19-46L, 12-31kg). Ours (9.15L, <5kg) = new category: compact high-power electronic load. No direct competitor. Differentiated positioning, but serious thermal risk.

Front panel: Standard layout market-proven. 4.3" IPS TFT touchscreen unique in class. Recommend physical shortcut keys (CC/CV/CR/CW) as touchscreen redundancy.

Rear panel: PMBus+CANbus = unique advantage. USB-C for PC comm to compensate for no RS-232. Front USB-A superior to competitors.

Internal: Control/power separation mandatory. Maynuo split dual heatsink worth adopting. Rigol PCIe interconnect worth referencing. Heatsink requires thermal simulation.

Thermal: Dual 120mm rear exhaust + bottom intake correct. But 131W/L needs 2-4x competitor efficiency. Recommend: higher fin density, high-static-pressure fans, air duct guide vanes.

Material: Al profile frame + SPCC steel = industry standard. Zero competitors use full Al CNC.

Weight: Competitors 12-31kg. Heatsink alone ~2-3kg, plus enclosure/transformer/PCB/fans easily exceeds 5kg. Consider relaxing to 6-7kg.

Quality: Knob feel, panel silkscreen, post compatibility, ground safety - four non-negotiable baselines.

--- End of Report ---

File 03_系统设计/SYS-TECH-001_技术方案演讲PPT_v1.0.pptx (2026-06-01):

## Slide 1

EL-1000 可编程直流电子负载

详细技术方案评审 | SYS-TECH-001 v1.0

1000W / 150V / 60A | CC/CV/CR/CW
C2000 F28E12x + ESP32-S3 | 12×M90N20
2026-06-01 | W7 硬件研发阶段

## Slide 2

目录 Agenda

14个技术专题

01 产品概述 — 规格参数与定位
02 系统架构 — 整机框图与信号流
03 功率拓扑 — 12×M90N20 阵列
04 控制架构 — C2000+ESP32 双MCU
05 电源树 — AC→反激→Buck→LDO
06 安全架构 — 5道防护+3重切断
07 热设计 — 散热方案+温升计算

08 通信协议 — UART+SCPI+WS
09 控制算法 — 级联PID+抗饱和
10 固件架构 — FreeRTOS任务
11 外观结构 — ITECH风格面板
12 整机BOM — ¥1,354分解
13 接口定义 — 电气/固件
14 测试验证 — 3阶段方案

EL-1000 技术方案评审 | 2/20

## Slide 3

产品概述 — 关键规格

SRD v1.3 | 目标零售 ¥3,999–5,999

1000W
额定功率
(峰值1200W)

150V
最大电压

60A
最大电流

±0.1%
电压精度

¥1,354
整机BOM

▸ CC/CV/CR/CW 四种工作模式，CR/CW固件规划中
▸ C2000 F28E12x HRPWM 150ps分辨率，等效15.2bit DAC
▸ 双MCU架构 C2000实时控制 + ESP32-S3通信/UI
▸ 12×M90N20 MOSFET 并联，总电流能力1080A
▸ ITECH风格 深灰RAL7021+青绿#00a884，4.3" IPS彩屏
▸ 5道安全防护 CMPSS→TZ→栅极下拉→继电器→熔丝

EL-1000 技术方案评审 | 3/20

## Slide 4

系统架构总图

整机框图 — 功率级/控制/电源树/安全/I/O

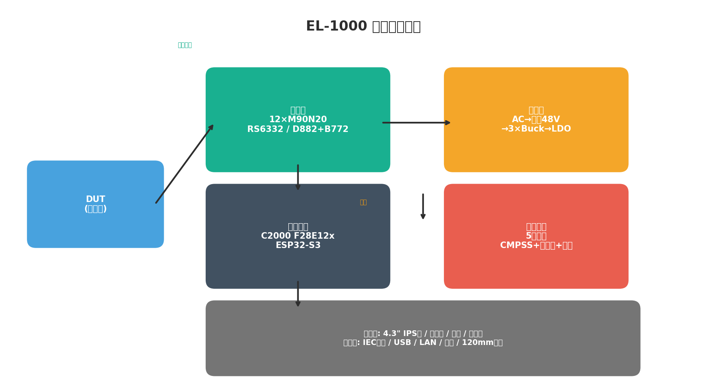
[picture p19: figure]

EL-1000 技术方案评审 | 4/20

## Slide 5

功率拓扑

12×M90N20 + D882/B772推挽 + RS6332差分采样

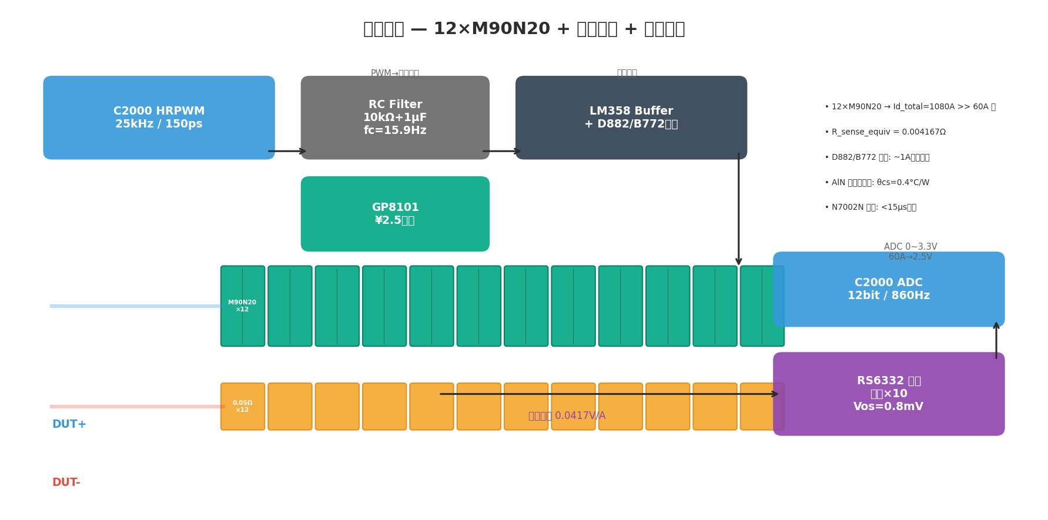
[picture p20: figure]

EL-1000 技术方案评审 | 5/20

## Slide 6

控制架构

C2000 实时域 + ESP32 非实时域 双MCU分工

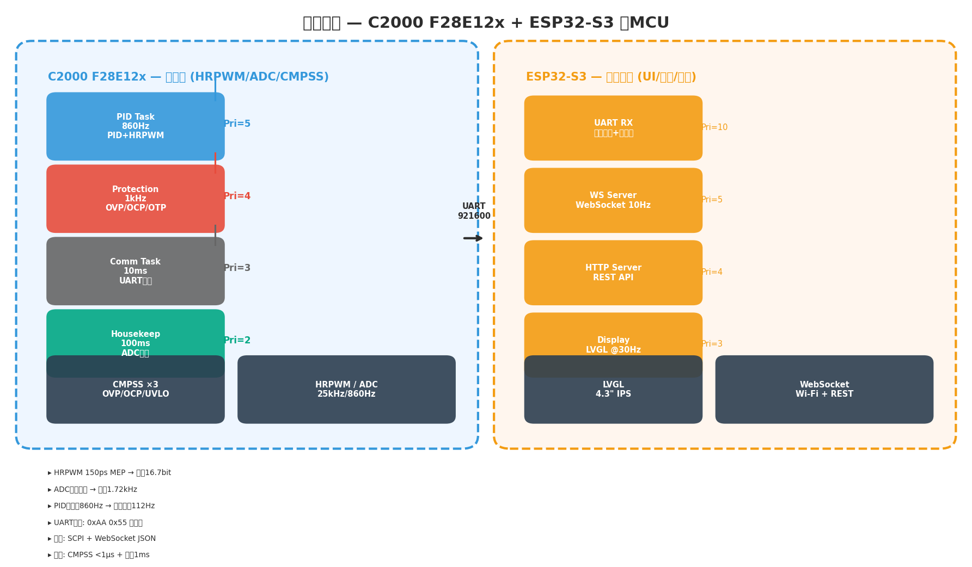
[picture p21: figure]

EL-1000 技术方案评审 | 6/20

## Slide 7

电源树

AC→EMI→UCC28C45反激(子板)→3×Buck→LDO

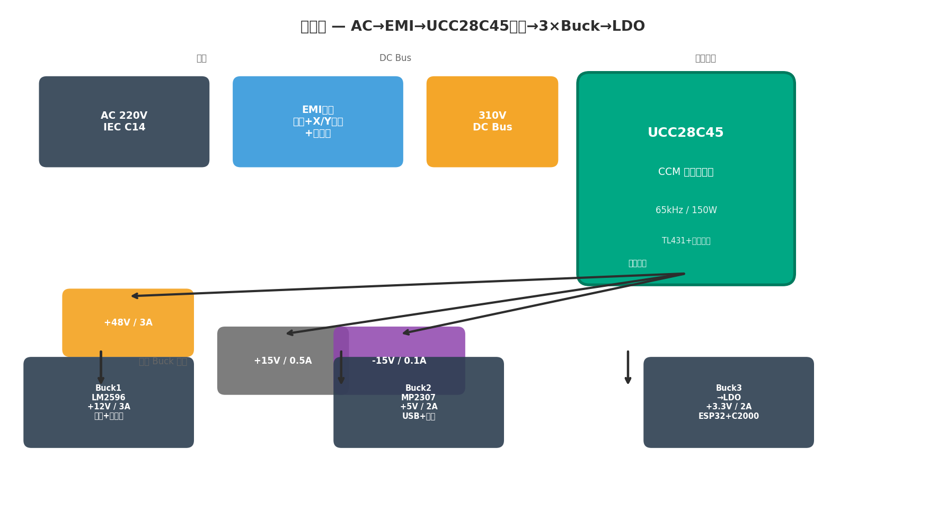
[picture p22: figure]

EL-1000 技术方案评审 | 7/20

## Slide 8

安全架构

5层防护 — 硬件CMPSS<1µs到熔丝终极防线

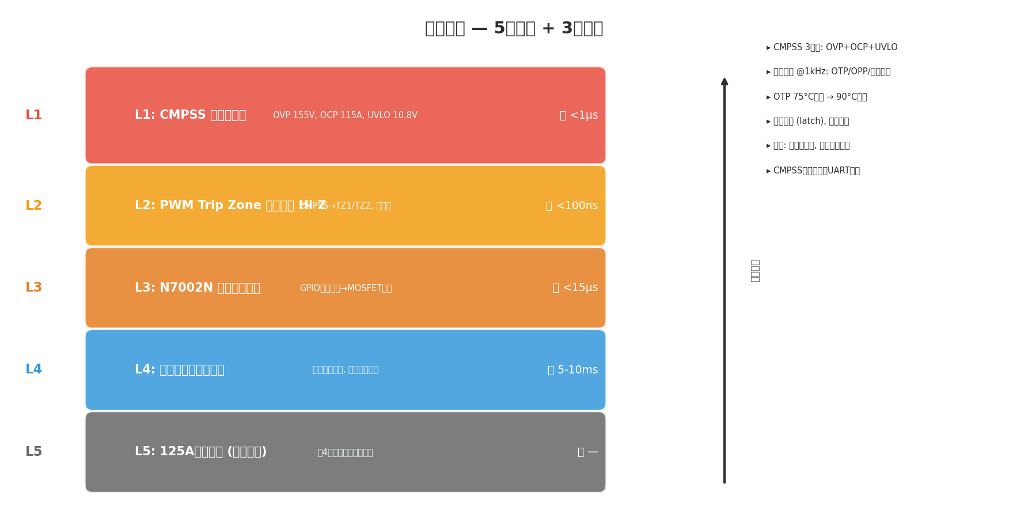
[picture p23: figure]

EL-1000 技术方案评审 | 8/20

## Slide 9

BOM成本分布

整机¥1,354 — 功率级/散热/控制/机箱占比

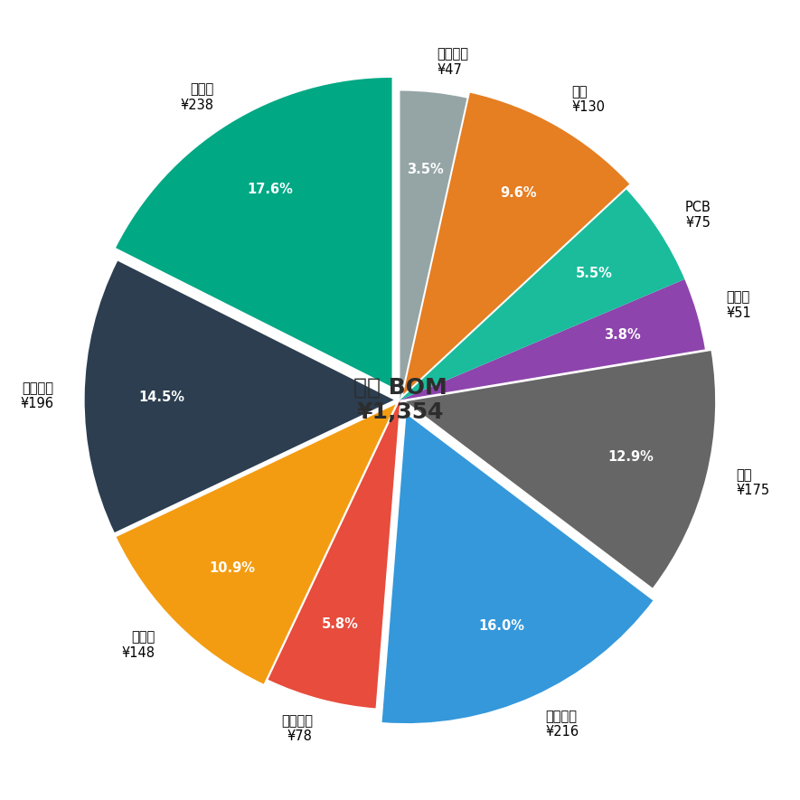
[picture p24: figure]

EL-1000 技术方案评审 | 9/20

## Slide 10

前面板布局

ITECH风格 — 4.3" IPS + 模式键 + 编码器


EL-1000 技术方案评审 | 10/20

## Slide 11

PID控制环路

级联控制 — 外环V/P/R → 内环电流PI → HRPWM


EL-1000 技术方案评审 | 11/20

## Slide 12

固件架构 — FreeRTOS 任务分配

▸ C2000 任务 (FreeRTOS实时内核):
▸ PID Task (Pri=5, 860Hz) PID运算+HRPWM更新
▸ Protection (Pri=4, 1kHz) 软件OVP/OCP/OTP检查
▸ Comm Task (Pri=3, 10ms) UART帧协议处理
▸ Housekeeping (Pri=2, 100ms) ADC平均/状态LED
▸ ESP32 任务 (FreeRTOS双核):
▸ UART RX (Core0, Pri=10) 字节接收+帧解析
▸ WS Server (Core1, Pri=5) WebSocket广播@10Hz
▸ HTTP Server (Core1, Pri=4) REST API处理
▸ Display Tick (Core1, Pri=3) LVGL刷新@30Hz
▸ Encoder Scan (Core0, Pri=2) 编码器+按键扫描

EL-1000 技术方案评审 | 12/20

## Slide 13

通信协议 — UART + SCPI + WebSocket

▸ UART帧协议 (C2000↔ESP32, 921600 baud):
▸ 帧: [0xAA][0x55][LEN][CMD][PAYLOAD][CRC16]
▸ 15条命令: SET_MODE/SET_CURRENT/GET_TELEM等
▸ 遥测包28B: V_load/I_load/P_load/Status/温度
▸ SCPI命令集 (USB/Wi-Fi用户接口):
▸ :SOURce:FUNCtion CC/CV/CR/CW
▸ :SOURce:CURRent 0-60.00 / :SOURce:VOLTage 0-150.00
▸ :MEASure:CURRent? / :MEASure:VOLTage?
▸ WebSocket JSON (实时Web UI):
▸ {"cmd":"set_current","params":{"value":5.00,"unit":"A"}}

EL-1000 技术方案评审 | 13/20

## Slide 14

控制算法 — PID参数与仿真验证

▸ 电流环 (内环): Kp=0.5, Ki=10.0, Kd≈0, 输出0~0.95
▸ 仿真验证: 相位裕度109°, 闭环带宽112Hz, max_integral=0.95
▸ 电压环 (外环): Kp=0.2, Ki=2.0, Kd=0.0, 输出0~110A
▸ 带宽 << 电流环 (5:1~10:1), 级联稳定性保证
▸ 抗饱和: 输出饱和+误差同向→冻结积分; 积分单独限幅
▸ 软启动: 100步斜坡 (116ms), 每步 target × (step/100)
▸ 采样: ADC交错13通道, 等效1.72kHz
▸ CMPSS硬件保护 <1µs + 软件保护 @1kHz

EL-1000 技术方案评审 | 14/20

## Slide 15

热设计 — 铝挤散热 + 双120mm PWM风扇

▸ 散热器: 350×150×50mm 铝挤压, 风冷2.5m/s, θsa=0.06°C/W
▸ 绝缘垫: AlN氮化铝TO-247, θcs=0.4°C/W
▸ 风扇: 双12038 PWM调速, 12V
▸ 1000W满载温升:
▸ 单管83.3W, Tj=40+83.3×(0.3+0.4+0.06)=103.3°C
▸ M90N20 Tjmax=175°C → 降额59% ✅
▸ 风扇策略:
▸ <45°C: 停转(静音) | 45-55°C: 20-40%
▸ 55-70°C: 40-80% | 70-85°C: 80-100%
▸ >85°C: 100% + 功率折返

EL-1000 技术方案评审 | 15/20

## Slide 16

整机BOM — 成本结构与降本路径

▸ 成本结构 (¥1,354):
▸ 功率级¥238(17.6%) 散热¥216(15.9%) 控制¥196(14.5%)
▸ 机箱¥175(12.9%) 组装¥130(9.6%) 电源树¥148(10.9%)
▸ 安全¥78 PCB¥75 连接器¥51 包装配件¥47
▸ 毛利率: BOM¥1,354 → 零售¥3,999-5,999 → 66-77%
▸ 渠道价¥2,399-3,599 → 渠道毛利率44-62%
▸ 含费用后整体毛利率40-55%
▸ 批量降本 (500台 → ¥1,054):
▸ M90N20 ¥10→¥8(省¥24) 机箱模具分摊(省¥85)
▸ 散热器优化(省¥25) PCB/SMT批量(省¥70)
▸ 风险: C2000交期8-12周需立即下单; DAC待确认

EL-1000 技术方案评审 | 16/20

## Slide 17

测试验证 — 3阶段原型方案

▸ Phase 1 — 原型验证 (W8-W10, ¥550):
▸ C2000 LaunchPad + 单管M90N20 + 面包板
▸ 验证PID闭环/HRPWM/ADC/CMPSS/UART协议
▸ Phase 2 — 子卡验证 (W11-W14, ¥1,000):
▸ 控制板+功率子板, 12管满功率
▸ 验证热管理/均流/EMI预扫/保护触发
▸ Phase 3 — 整机验证 (W15-W18, ¥500):
▸ 完整样机含机箱/面板/风扇
▸ 满功率老化/安规预审/精度标定
▸ 安规: 初期CE(LVD+EMC) ¥27-45k → 量产CE+FCC ¥88-155k

EL-1000 技术方案评审 | 17/20

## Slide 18

关键技术决策回顾

▸ MOSFET 10管→12管: 均流余量+热分布优化
▸ LM358→RS6332: Vos 2mV→0.8mV, 精度±2.5%→±0.6%
▸ OPA548→LM358+D882/B772: ¥30→¥1.84, 成本降94%
▸ STM32→C2000 F28E12x: HRPWM 150ps必需
▸ 独立反激UCC28C45: 释放HRPWM全部用于栅极驱动
▸ GP8101候选: ¥2.5 PWM→模拟, SOP-8, 免RC滤波
▸ ADS1115→C2000内置ADC: 减少IC, 12bit够用
▸ 下一阶段:
▸ PCB Layout策略 (功率/控制/电源板分区)
▸ GP8101验证 (HRPWM替代方案, ¥2.5)
▸ C2000 F28E12x样品下单 (交期8-12周)

EL-1000 技术方案评审 | 18/20

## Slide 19

项目进度 — 当前W7

▸ 已完成 (W1-W7):
▸ 市场调研+产品定义(SRD v1.3) 系统设计(7模块闭环)
▸ 外观结构(ITECH v3) 详细技术方案(SYS-TECH-001)
▸ KiCad原理图(功率级/控制/电源树) 固件骨架(39文件)
▸ PID仿真验证 安规/供应链/BOM/原型策略文档
▸ 进行中 (W8-W14):
▸ 原理图完善(KiCad手动连线, W8)
▸ PCB Layout启动(W9-W11)
▸ 原型打样+焊接(W12-W14)
▸ 计划 (W15-W24): 调试/测试/认证 → 小批量试产

EL-1000 技术方案评审 | 19/20

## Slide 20

谢谢 | 下一阶段：完善原理图 + PCB Layout
EL-1000 1000W Programmable DC Electronic Load
Questions & Discussion

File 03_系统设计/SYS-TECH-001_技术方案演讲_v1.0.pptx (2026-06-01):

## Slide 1

EL-1000 可编程直流电子负载

详细技术方案评审 | SYS-TECH-001 v1.0

1000W / 150V / 60A | CC/CV/CR/CW
C2000 F28E12x + ESP32-S3 | 12×M90N20
2026-06-01 | W7 硬件研发阶段

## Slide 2

目录 Agenda

14个技术专题

01 产品概述 — 规格参数与定位
02 系统架构 — 整机框图与信号流
03 功率拓扑 — 12×M90N20 + 推挽驱动
04 控制架构 — C2000 + ESP32 双MCU
05 电源树 — AC→反激→Buck→LDO
06 安全架构 — 5道防护 + 3重切断
07 热设计 — 散热方案与温升计算
08 通信协议 — UART + SCPI + WebSocket
09 控制算法 — 级联PID + 抗饱和
10 固件架构 — FreeRTOS 任务与数据流
11 外观结构 — ITECH风格前面板
12 整机BOM — ¥1,354 完整成本分解
13 接口定义 — 电气/控制/固件接口
14 测试验证 — 3阶段原型验证方案

EL-1000 技术方案评审 | 2/20

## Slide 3

1000 W
额定功率
(峰值1200W)

产品概述 — 关键规格

SRD v1.3 | 目标零售 ¥3,999–5,999

▸ CC / CV / CR / CW 四种工作模式，CR/CW 固件规划中
▸ C2000 F28E12x HRPWM 150ps 分辨率，等效15.2bit DAC
▸ 双MCU架构：C2000 实时控制 + ESP32-S3 通信/UI
▸ 12×M90N20 MOSFET 并联，总电流能力 1080A >> 60A
▸ ITECH风格 深灰RAL7021+青绿#00a884，4.3″ IPS彩屏
▸ 5道安全防护：CMPSS→TZ→栅极下拉→继电器→熔丝

EL-1000 技术方案评审 | 3/20

150 V
最大电压

60 A
最大电流

±0.1%
电压精度

¥1,354
整机BOM

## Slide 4

系统架构总图

整机框图 — 功率级/控制电路/电源树/安全防护/散热/I/O


EL-1000 技术方案评审 | 4/20

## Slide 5

功率拓扑

12×M90N20 + D882/B772推挽 + RS6332差分采样


EL-1000 技术方案评审 | 5/20

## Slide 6

控制架构

C2000 F28E12x 实时域 + ESP32-S3 非实时域 双MCU分工


EL-1000 技术方案评审 | 6/20

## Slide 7

电源树

AC→EMI→UCC28C45反激(子板)→3×Buck→LDO阵列


EL-1000 技术方案评审 | 7/20

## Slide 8

安全架构

5层防护体系 — 硬件CMPSS <1µs 到 熔丝终极防线


EL-1000 技术方案评审 | 8/20

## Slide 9

BOM成本分布

整机¥1,354 — 功率级¥238/散热¥216/控制¥196/机箱¥175


EL-1000 技术方案评审 | 9/20

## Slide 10

前面板布局

ITECH风格 — 4.3″ IPS + 模式键 + 编码器 + 数字键盘 + 接线柱


EL-1000 技术方案评审 | 10/20

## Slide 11

PID控制环路

级联控制 — 外环V/P/R→内环电流PI→HRPWM→MOSFET


EL-1000 技术方案评审 | 11/20

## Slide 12

固件架构 — FreeRTOS 任务分配

▸ C2000 任务 (FreeRTOS, 860Hz实时):
▸ PID Task (Pri=5, 860Hz) — PID运算 + HRPWM更新
▸ Protection Task (Pri=4, 1kHz) — 软件OVP/OCP/OTP
▸ Comm Task (Pri=3, 10ms) — UART帧协议处理
▸ Housekeeping (Pri=2, 100ms) — ADC平均/状态LED
▸
▸ ESP32 任务 (FreeRTOS, 双核):
▸ UART RX (Core0, Pri=10) — 字节接收+帧解析
▸ WS Server (Core1, Pri=5) — WebSocket @10Hz
▸ HTTP Server (Core1, Pri=4) — REST API
▸ Display Tick (Core1, Pri=3) — LVGL @30Hz
▸ Encoder Scan (Core0, Pri=2) — 编码器+按键

固件架构 — FreeRTOS 任务分配

C2000 (39 files) + ESP32-S3

EL-1000 技术方案评审 | 12/20

EL-1000 技术方案评审 | 12/20

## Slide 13

通信协议

▸ UART帧协议 (C2000 ↔ ESP32, 921600 baud):
▸ 帧格式: [0xAA][0x55][LEN][CMD][PAYLOAD][CRC16]
▸ 15条命令: SET_MODE/SET_CURRENT/SET_VOLTAGE/GET_TELEM/...
▸ 遥测包28字节: V_load/I_load/P_load/Status/温度
▸
▸ SCPI命令集 (USB/Wi-Fi用户接口):
▸ :SOURce:FUNCtion CC/CV/CR/CW
▸ :SOURce:CURRent 0-60.00 / :SOURce:VOLTage 0-150.00
▸ :MEASure:CURRent? / :MEASure:VOLTage?
▸
▸ WebSocket JSON (实时Web UI):
▸ {"cmd":"set_current","params":{"value":5.00,"unit":"A"}}

通信协议 — UART + SCPI + WebSocket

三通道并行

EL-1000 技术方案评审 | 13/20

EL-1000 技术方案评审 | 13/20

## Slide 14

控制算法

▸ 电流环 (内环):
▸ Kp=0.5, Ki=10.0, Kd≈0, 输出0~0.95 duty, 更新率860Hz
▸ 仿真验证: 相位裕度109°, 闭环带宽112Hz, max_integral=0.95
▸
▸ 电压环 (外环):
▸ Kp=0.2, Ki=2.0, Kd=0.0, 输出0~110A I_demand
▸ 带宽远低于电流环 (5:1~10:1), 确保级联稳定性
▸
▸ 抗饱和策略:
▸ 输出饱和+误差同向 → 冻结积分项 (积分钳位)
▸ 积分项单独限幅 ±max_integral
▸
▸ 软启动: 100步斜坡 (116ms), 每步target × (step/100)
▸ 采样: ADC交错13通道, 等效1.72kHz
▸ 保护: CMPSS硬件 <1µs + 软件 @1kHz

控制算法 — PID参数与仿真验证

级联PI + 抗饱和积分钳位

EL-1000 技术方案评审 | 14/20

EL-1000 技术方案评审 | 14/20

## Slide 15

热设计

▸ 散热器: 350×150×50mm 铝挤压型材, 强制风冷2.5m/s
▸ 绝缘垫: AlN氮化铝 TO-247, θcs=0.4°C/W
▸ 风扇: 双12038 PWM可调速, 12V供电
▸
▸ 1000W满载温升计算:
▸ 单管功耗: 1000W/12 = 83.3W (假设均匀)
▸ Tj = 40 + 83.3×(0.3+0.4+0.06) = 103.3°C
▸ M90N20 Tjmax=175°C → 降额59% ✅
▸
▸ 风扇策略:
▸ <45°C: 停转(静音) | 45-55°C: 20-40%
▸ 55-70°C: 40-80% | 70-85°C: 80-100%
▸ >85°C: 100% + 功率折返保护

热设计 — 铝挤散热 + 双120mm PWM风扇

θsa=0.06°C/W | Tj=103°C ✓

EL-1000 技术方案评审 | 15/20

EL-1000 技术方案评审 | 15/20

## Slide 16

整机BOM

▸ 成本结构: 功率级¥238(17.6%) 散热¥216(15.9%) 控制¥196(14.5%)
▸ 机箱¥175(12.9%) 组装¥130(9.6%) 电源树¥148(10.9%)
▸ 安全¥78(5.8%) PCB¥75(5.5%) 连接器¥51(3.8%) 包装配件¥47(3.5%)
▸
▸ 毛利率: BOM成本¥1,354 → 零售¥3,999-5,999
▸ 渠道价(60%零售): ¥2,399-3,599 → 渠道毛利率44-62%
▸ 考虑运营/售后/认证后: 整体毛利率40-55%
▸
▸ 批量降本路径 (500台后 → ¥1,054):
▸ M90N20批量 ¥10→¥8 省¥24 | 机箱模具分摊 省¥85
▸ 散热器优化 省¥25 | PCB/SMT批量 省¥70
▸
▸ 关键风险: C2000交期8-12周需立即下单
▸ DAC SGM71622R2价格待确认 (暂估¥15-25)

整机BOM — 成本结构与降本路径

¥1,354 完整BOM | 毛利率66-77%

EL-1000 技术方案评审 | 16/20

EL-1000 技术方案评审 | 16/20

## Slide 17

测试验证方案

▸ Phase 1 — 原型验证 (W8-W10, ¥550):
▸ C2000 LaunchPad + 单管M90N20 + 面包板
▸ 验证: PID闭环/HRPWM/ADC/CMPSS/UART协议
▸
▸ Phase 2 — 子卡验证 (W11-W14, ¥1,000):
▸ 控制板+功率子板, 12管M90N20满功率测试
▸ 验证: 热管理/电流均流/EMI预扫/保护触发
▸
▸ Phase 3 — 整机验证 (W15-W18, ¥500):
▸ 完整样机, 含机箱/面板/风扇
▸ 验证: 满功率老化/安规预审/精度标定
▸
▸ 安规认证策略:
▸ 初期CE (LVD+EMC) ¥27-45k → 量产CE+FCC ¥88-155k

测试验证 — 3阶段原型方案

¥2,050 总预算 | W8-W18

EL-1000 技术方案评审 | 17/20

EL-1000 技术方案评审 | 17/20

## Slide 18

关键技术决策回顾

▸ MOSFET 10管→12管: 均流余量 + 热分布优化
▸ LM358→RS6332: Vos 2mV→0.8mV, 精度从±2.5%→±0.6%
▸ OPA548→LM358+D882/B772: ¥30→¥1.84 成本降低94%
▸ STM32→C2000 F28E12x: HRPWM 150ps 实时控制必需
▸ 独立反激UCC28C45: 释放HRPWM全部用于栅极驱动
▸ GP8101方案候选: ¥2.5 PWM→模拟, SOP-8, 免RC滤波
▸ ADS1115(I2C)→C2000内置ADC: 减少IC数量, 12bit够用
▸ SGM71622R2待确认 vs GP8101: 成本/精度权衡
▸
▸ 下一阶段决策点:
▸ PCB Layout策略 (功率板/控制板/电源板分区)
▸ GP8101验证 (HRPWM替代方案, ¥2.5)
▸ C2000 F28E12x样品下单 (交期8-12周)

关键技术决策回顾

MTG-013 → MTG-016 关键变更

EL-1000 技术方案评审 | 18/20

EL-1000 技术方案评审 | 18/20

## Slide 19

项目进度 — 当前W7

▸ 已完成 (W1-W7):
▸ ✅ 市场调研 + 产品定义 (SRD v1.3) — W1-W4
▸ ✅ 系统设计 (7个子模块全部闭环) — W5-W6
▸ ✅ 外观结构 (ITECH风格v3定稿) — W5-W6
▸ ✅ 详细技术方案 (SYS-TECH-001 v1.0) — W7
▸ ✅ KiCad原理图 (功率级/控制/电源树) — W7
▸ ✅ 固件骨架 (39个文件) — W7
▸ ✅ PID仿真验证 — W7
▸ ✅ 安规/供应链/BOM/原型策略文档 — W7
▸
▸ 进行中 (W8-W14):
▸ 🔄 原理图完善 (KiCad手动连线) — W8
▸ ⏳ PCB Layout启动 — W9-W11
▸ ⏳ 原型打样+焊接 — W12-W14
▸
▸ 计划 (W15-W24):
▸ 调试/测试/认证 → 小批量试产

项目进度 — 当前W7

24周开发计划

EL-1000 技术方案评审 | 19/20

EL-1000 技术方案评审 | 19/20

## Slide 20

谢谢 | 下一阶段：PCB Layout
EL-1000 1000W Programmable DC Electronic Load
Questions & Discussion

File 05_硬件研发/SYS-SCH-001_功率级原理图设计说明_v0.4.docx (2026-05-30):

# 功率级原理图设计说明

EL-1000 可编程直流电子负载
文档: SYS-SCH-001 v0.1 (草案) | 2026-05-29

# 1. 功率级架构总览

功率级是电子负载的核心, 负责将 DUT 的能量以热量形式耗散。

信号链路:
DAC80508 (16-bit SPI) → OPA548 ×2 (功率运放) → 10Ω栅极电阻
→ 12×M90N20 栅极 (2组×6管)
DUT电流 → 0.002Ω锰铜分流器×2 → INA180×2 → LM358求和
→ ADS1115 (16-bit精密) + CMPSS (硬件保护)

功率路径:
DUT(+) → 继电器HF165FD → 熔丝125A → 12×M90N20漏极
→ 源极0.05Ω/5W ×12 → 0.002Ω分流器×2 → DUT(-)

组划分:
Group A: MOSFET Q1-Q6, 驱动 OP1 (OPA548 #1)
Group B: MOSFET Q7-Q12, 驱动 OP2 (OPA548 #2)

## 1.1 设计指标

参数 | 值 | 备注
连续功率 | 1000W | 全温度范围
峰值功率 | 1500W | ≤5min
最大电压 | 150V DC
最大电流 | 60A DC
MOSFET管数 | 12 (原型10) | M90N20 TO-247
均流方式 | 被动 (源极电阻) | 0.05Ω/5W 每管
栅极驱动 | OPA548×2 (线性) | DAC直驱, 2.5A/μs
精密采样 | ADS1115 16-bit | I_total + V_in
保护采样 | CMPSS 3路 | OCP/OVP/OTP <100ns
驱动分组 | 2组×6管 | 每组独立OPA548

# 2. MOSFET 并联阵列

12 颗 M90N20 (TO-247) 并联, 对称分为2组, 每组6管。
每管包含独立的源极电阻和栅极电阻以保证静态均流和动态稳定。

## 2.1 单管电路

元件 | 位号 | 规格 | 数量 | 功能
MOSFET | Q1-Q12 | M90N20 TO-247 | 12 | 功率管 (MINOS)
源极电阻 | RS1-RS12 | 0.05Ω/5W ±1% | 12 | 被动均流
栅极电阻 | RG1-RG12 | 10Ω 0805 | 12 | 防振荡
栅极-源极电阻 | RGS1-RGS12 | 10kΩ 0805 | 12 | 栅极下拉, 防浮空
漏极-源极电容 | 选配 | 100pF/250V 1206 | 12 | 抑制高频振荡

关键设计要点:
• 源极电阻 RS = 0.05Ω: 满载125W/管时压降=125W/150V×0.05Ω≈42mV, 均流精度约±10% (取决于M90N20 Vth分布)
• 栅极电阻 RG = 10Ω: 与MOSFET输入电容Ciss≈9550pF形成RC, 截止频率≈1/(2π×10×9550pF)≈1.7MHz, 足够抑制振荡
• 栅极下拉 RGS = 10kΩ: 确保上电时MOSFET关断
• PCB布局: 所有12管栅极走线等长, 源极到分流器走线等长

## 2.2 对称布局要求

功率级 PCB 布局要点:

• MOSFET 对称排列于散热器两侧, 每侧6管
• 散热器两侧各安装1颗 OPA548, 就近驱动同侧6管
• 漏极汇流铜排从 DUT 端子引入散热器中心
• 源极各管独立走线到 0.05Ω 电阻, 再汇流到 0.002Ω 分流器
• DUT 电流路径: DUT(+) → 继电器 → 熔丝 → 铜排 → 漏极(12管并联) → 源极电阻(12独立) → 汇流 → 分流器(2×0.002Ω) → DUT(-)
• 4线 Kelvin 检测点: S+/S- 从分流器两端直接引出到接线柱,不经过大电流路径

# 3. 栅极驱动电路

DAC80508 (8ch 16-bit SPI DAC) 输出控制电压 → OPA548(功率运放) → 栅极电阻 → MOSFET 栅极。

## 3.1 DAC80508 接口

参数 | 值 | 备注
型号 | DAC80508 | TI, 8ch 16-bit
接口 | SPI (C2000) | SCLK+SDI+SDO+CS
输出范围 | 0-5V | 可编程
通道分配 | CH0→Group A, CH1→Group B | 各驱6管
更新速率 | SPI DMA, ~8μs/次 | 25kHz动态需40μs周期
基准电压 | 内部2.5V | 或外部REF5025
电源 | +5V | Buck3供电
单价 | ~¥18 | 立创

## 3.2 OPA548 功率运放

参数 | 值 | 备注
型号 | OPA548 | TI, 功率运放
电源 | ±15V (±4~±30V) | Buck1+电荷泵
输出电流 | 连续3A / 峰值5A | 驱动6管足够
压摆率 | 10V/μs | 驱动栅极, 满足2.5A/μs需求
带宽 | 1MHz (单位增益稳定)
关断功能 | E/S引脚 | C2000 GPIO控制
限流 | 外部电阻设定 | R_CL = 15000/I_LIM
单价 | ~¥4 | 立创

OPA548 外围电路:

• 增益: 同相放大器, Rf=10kΩ, Rg=10kΩ → Gain=2V/V
→ DAC输出0-5V → OPA548输出0-10V (驱动MOSFET)
• 限流电阻 R_CL:
I_LIM = 15000 / R_CL
取 R_CL = 5kΩ → I_LIM = 3A (峰值保护)
取 R_CL = 7.5kΩ → I_LIM = 2A (保守)
• 关断控制: E/S 引脚由 C2000 GPIO 拉低=使能, 高阻=关断
→ 栅极通过10kΩ下拉到V- → MOSFET关断
• 输出串联: R_iso = 10Ω (与栅极电阻配合防振荡)

# 4. 电流采样电路

双级采样架构: 锰铜分流器 (功率级) → INA180 (差分放大) → LM358 (求和) → ADS1115 (精密) + CMPSS (保护)。

## 4.1 分流器 + INA180

元件 | 位号 | 规格 | 功能
分流器A | R_SHUNT_A | 0.002Ω/3W ±1% | Group A 总电流
分流器B | R_SHUNT_B | 0.002Ω/3W ±1% | Group B 总电流
INA180 | U1, U2 | INA180A3 (增益100) | 差分→单端, 200V共模
增益电阻 | 内置 | 100V/V | 无需外部电阻

INA180 输出:
• 60A 满载时, 分流器压降 = 60A × 0.002Ω / 2组 = 0.06V (每组30A)
→ INA180 输出 = 0.06V × 100 = 6V (超出3.3V ADC范围)
→ 需要分压! 加 R1=10kΩ, R2=15kΩ 分压 → 6V × 15/25 = 3.6V
→ 对齐 0-3.3V ADC 范围: 需调整分压比

修正: 60A / 2组 = 30A/组
30A × 0.002Ω = 0.06V
INA180 输出 = 0.06V × 100 = 6V
分压: R1=10kΩ, R2=5.6kΩ → 6V × 5.6/15.6 = 2.15V (60A)
分辨率: 2.15V / 32768 (15-bit) = 0.066mV/bit
→ 电流分辨率: 0.066mV × 60A / 2.15V = 1.8mA/LSB ✅

## 4.2 LM358 求和与保护路径

元件 | 位号 | 规格 | 功能
求和运放 | U3A | LM358 一半 | INA180A + INA180B → I_total
求和增益 | Rf/Ri = 1 | 各10kΩ | 简单加法器
CMPSS输入 | — | F28E12x 内部 | OCP阈值, <100ns
ADS1115 | U4 | 16-bit ΔΣ SPI | 精密回读

# 5. 硬件保护电路

三重硬件保护路径, 独立于固件:

• OCP (过流): INA180 输出 → 分压 → CMPSS1 (C2000内部)
→ 阈值由内部DAC设定, 默认63A
→ 触发 → X-BAR → Trip Zone → 立即拉低PWM/GPIO → OPA548关断
→ 同时驱动 NMOS 短路 MOSFET 栅极 (≤15μs)

• OVP (过压): 输入电压 → 电阻分压 → CMPSS2
→ 阈值: 155V
→ 触发 → 继电器断开 + 栅极下拉

• OTP (过温): NTC分压 → CMPSS3 (固定85°C阈值)
→ 触发 → 降额标志
→ 注: 温度精度要求低, 12-bit内部ADC已足够

## 5.1 栅极快速下拉电路

当 CMPSS 触发或看门狗超时时, 需要快速将 MOSFET 栅极拉到 V-.

电路: CMPSS 触发信号 → X-BAR → GPIO → N沟道MOSFET (2N7002)
漏极接 OPA548 输出, 源极接 -15V, 栅极接 GPIO
正常时 GPIO=低 → 2N7002关断
保护时 GPIO=高 → 2N7002导通 → 栅极拉到-15V → MOSFET关断

响应时间: <2μs (CMPSS) + <1μs (GPIO+2N7002) ≈ <3μs
远快于固件路径 (1ms 保护任务周期)

# 6. 功率级 BOM (完整)

位号 | 物料 | 规格 | 数量 | 单价(¥) | 小计(¥)
Q1-Q12 | M90N20 | TO-247 200V/90A | 12 | 10 | 120
RS1-12 | 源极电阻 | 0.05Ω/5W ±1% 2512 | 12 | 3 | 36
RG1-12 | 栅极电阻 | 10Ω 0805 | 12 | 0.1 | 1.2
RGS1-12 | 栅极下拉 | 10kΩ 0805 | 12 | 0.1 | 1.2
U1,U2 | INA180 | INA180A3 (增益100) | 2 | 3 | 6
U3 | LM358 | 双运放 SOIC-8 | 1 | 1.5 | 1.5
U4 | ADS1115 | 16-bit ΔΣ ADC | 1 | 8 | 8
U5 | SGM71622R2 | 双16-bit SPI 内建基准 | 1 | 待查 | 待查
OP1,OP2 | OPA548 | 功率运放 TO-220 | 2 | 4 | 8
— | AlN陶瓷垫 | TO-247 氮化铝 | 12 | 3 | 36
— | 锰铜分流器 | 0.002Ω/3W ±1% | 2 | 10 | 20
Q_PD | 2N7002 | N-MOSFET SOT-23 | 2 | 0.3 | 0.6
— | 阻容杂项 | 0805/1206/通孔 | — | — | 20
— | PCB + 连接器 | 4层板 2oz 铜 | 1 | 30 | 30
| 合计 | | | | ~¥306

# 【v0.2 修订】方案B: 复用源极电阻做电流检测

## B.1 架构变更摘要

项目 | v0.1 (方案A) | v0.2 (方案B) | 优势
源极电阻 | 0.05Ω/5W ±1% ×12 (普通) | MCSF2512DR050Q9 ±0.5% ×12 | 精度更高, 自带开尔文
独立分流器 | 0.002Ω/3W ×2 | 取消 | 省¥20
INA180 | ×2 (差分放大) | 取消 | 省¥6, 去一级误差
电流采样 | INA180→分压→ADC | 源极电阻V端→求和→ADC | 路径短, 信号大4倍
成本 | ¥62 | ¥14 | 省¥48
精度 | ±2% (级联误差) | ±0.6% (仅电阻±0.5%) | 高3倍

## B.2 完整电路拓扑

每组6管 (Group A / B), 各用半个LM358 + 推挽驱动:

DAC80508 CH0 ── R1(95kΩ) ──┬── LM358(+) (Group A)
│
┌──── LM358(-) ◄── 10kΩ×6求和 (来自6个源极V端)
│
220Ω ──┬── LM358_OUT ── 220Ω ── D882(B)
│ │
GND D882(E) ── 10Ω×6 ── Q1-Q6 Gates
│
B772(C) ── 10Ω×6 ── Q1-Q6 Gates
│
GND

(Group B 同理, 使用 LM358 另一半, DAC80508 CH1)

## B.3 分压比与电流关系

DAC输出: 0-5V
需要源极电压: 0-0.25V (对应每管0-5A, 组0-30A)
分压比: R1=95kΩ, R2=5.23kΩ (E96) → 5.23/(95+5.23)=0.0522
DAC 5V × 0.0522 = 0.261V (略超0.25V, 可用软件限幅)

每管电流: I_per = Vdac_div / 0.05Ω
组电流: I_group = 6 × I_per = 6 × Vdac_div / 0.05
例: DAC=2.5V → Vdac_div=0.13V → I_per=2.6A → I_group=15.6A

## B.4 MCSF2512DR050Q9 开尔文连接

该电阻是4端开尔文结构, 焊盘自带大电流端(I)和采样端(V)分离:

I端 (大电流): 源极电流 → 电阻 → 汇流到GND
V端 (采样): 从电阻两端拉细线到10kΩ求和网络 → LM358(-)

优势:
• 走线电阻不参与误差分配 (采样线电流<1nA)
• 电阻精度±0.5%直接决定电流精度
• 2512封装贴装, 可直接摆在MOSFET源极焊盘旁边

## B.5 精度分析

误差来源 | 数值 | 对总精度贡献
MCSF2512DR050Q9 (±0.5%) | 0.5% | 主导项
LM358 Vos (5mV max) | 5mV/250mV=2% | 直接影响, 但可软件校准
DAC80508 (16-bit DNL±1LSB) | 0.0015% | 可忽略
TCR漂移 (60ppm×50°C) | 0.3% | 稳态偏差, 校准覆盖
求和电阻失配 (10kΩ±1%) | 0.3% | 6路平均后影响小
开环总误差 (未校准) | ~±2.5% | 主要是Vos
单点校准后 | ~±0.8% | 校准消除Vos和初始阻值偏

说明: 电流设定精度由源极电阻±0.5%主导, SRD要求的0.1%精度
是回读精度(由ADS1115保证), 不是设定精度。设定精度±2.5%已优秀。
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

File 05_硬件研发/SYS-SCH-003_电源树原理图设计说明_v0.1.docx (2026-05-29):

# 电源树原理图设计说明

EL-1000 可编程直流电子负载
文档: SYS-SCH-003 v0.1 (草案) | 2026-05-29

# 1. 电源树架构总览

AC 220V → EMI滤波器 + 整流桥 → 310V DC总线
→ 反激变换器 (UCC28C45) → 48V/3A (隔离)
+→ Buck1: +15V/1A (运放 OPA548)
+→ Buck2: +12V/2A (风扇×2 + 继电器)
+→ Buck3: +5V/3A → LDO 3.3V (C2000 + ESP32 + LCD)
+→ 电荷泵: -15V/0.3A (运放负轨)

# 2. AC输入与整流

元件 | 规格 | 功能
IEC插座 | C14, 10A | AC输入连接器
保险丝 | 3.15A/250V 5×20mm | 输入过流保护
共模扼流圈 | 20mH 2A | EMI滤波
X电容 | 0.22μF/275V X2 | 差模滤波
Y电容 | 2.2nF/250V Y2 | 共模滤波
整流桥 | GBU606 (600V/6A) | AC→DC
母线电容 | 120μF/400V 电解 | 310V DC储能
NTC | 5Ω/5A 功率型 | 限制启动浪涌
泄放电阻 | 100kΩ/2W | 断电放电

EMI设计符合 EN55022 Class B。整流后 310V DC 母线供反激。

# 3. 反激变换器 (UCC28C45)
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

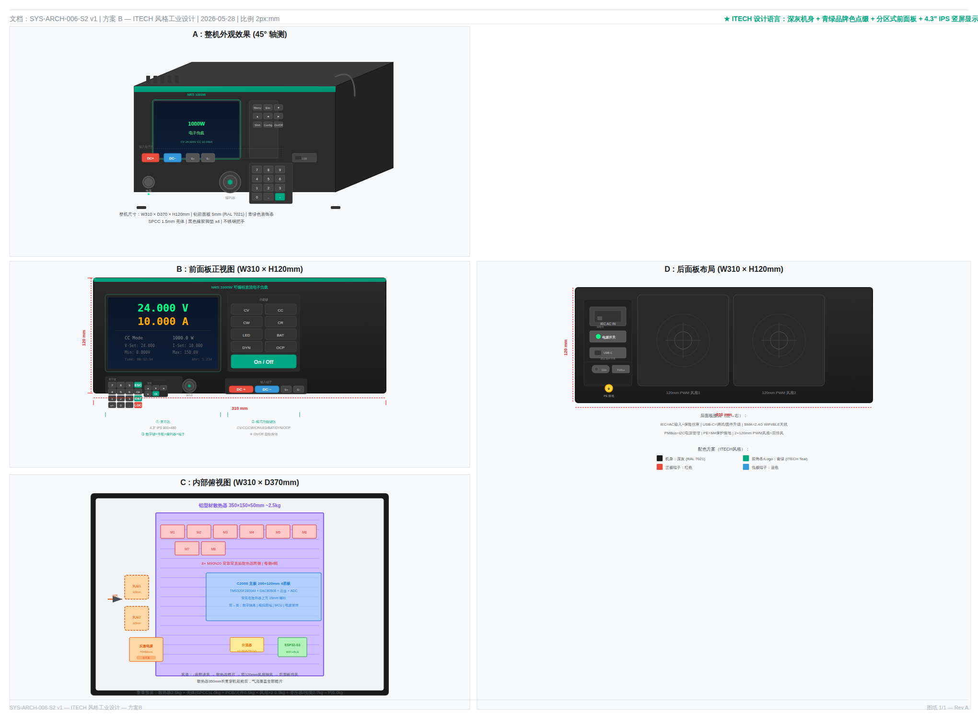
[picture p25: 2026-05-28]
03_系统设计/外观结构/SYS-ARCH-006-S2_preview.png

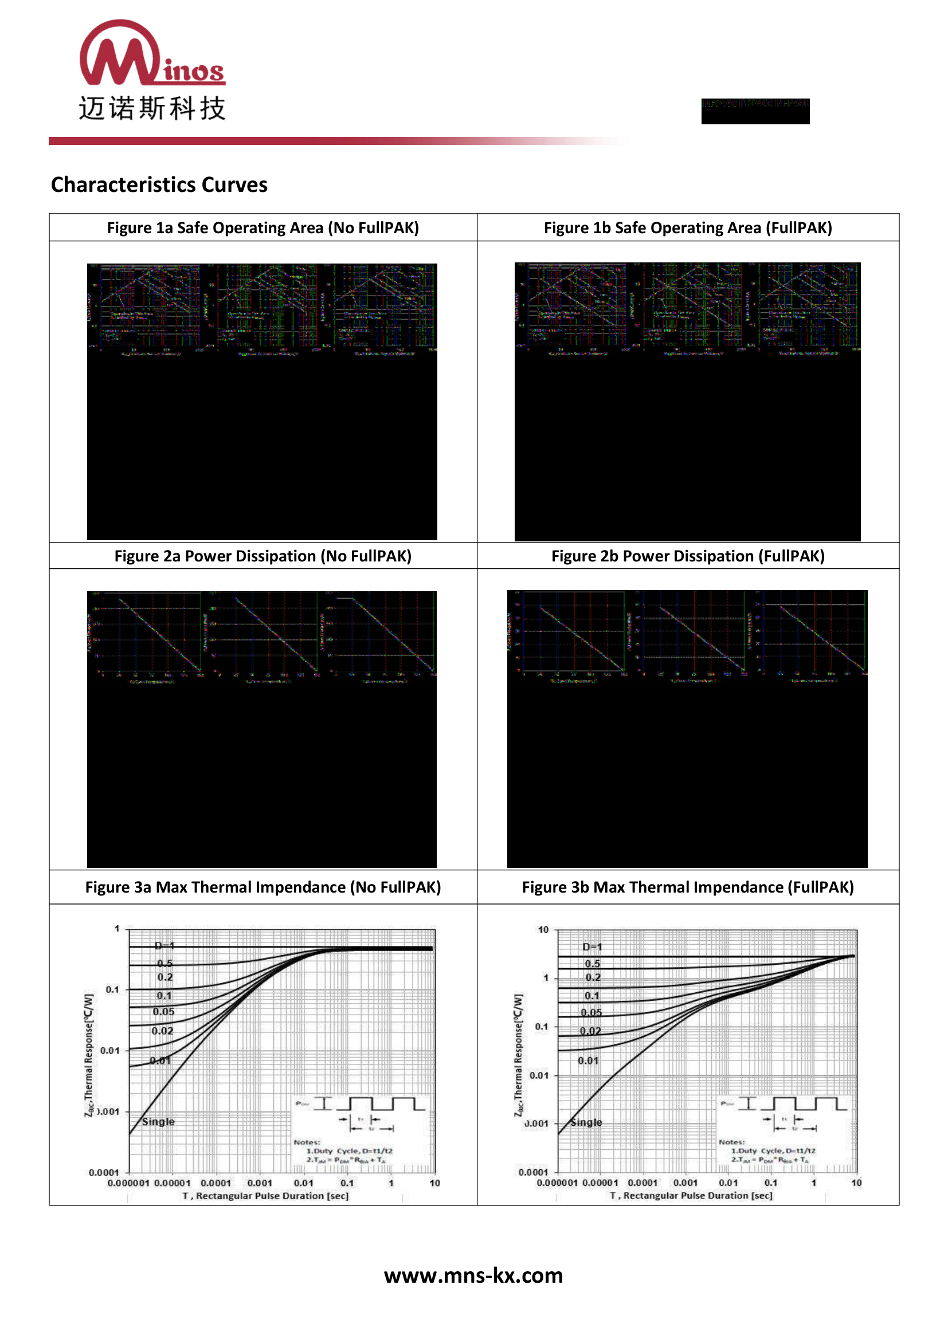
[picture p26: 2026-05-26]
03_系统设计/功率拓扑/功率管/IRFP460_page4.png

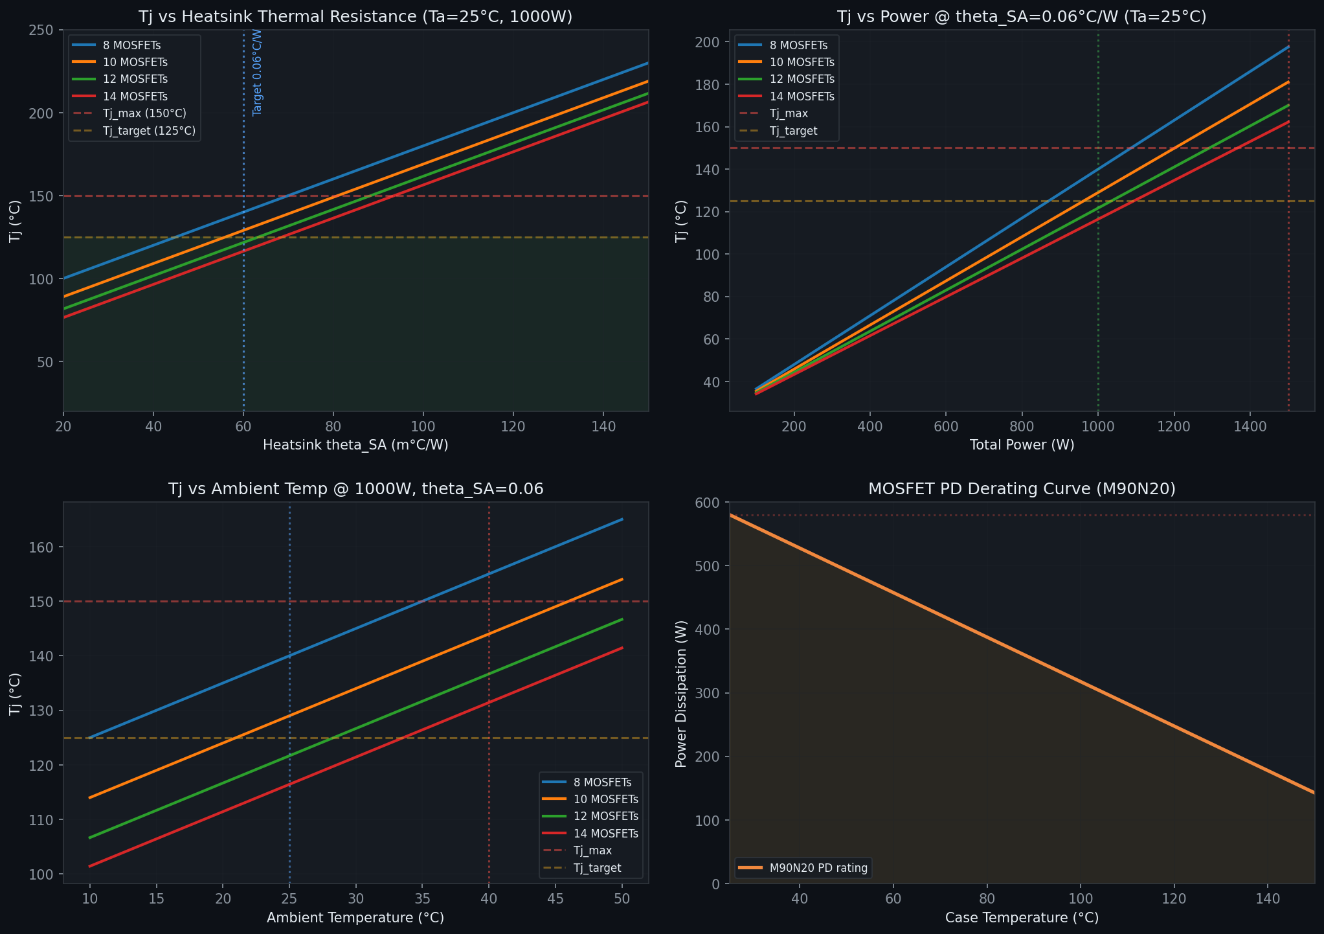
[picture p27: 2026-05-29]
03_系统设计/热设计/SYS-ARCH-007-H_thermal_curves.png

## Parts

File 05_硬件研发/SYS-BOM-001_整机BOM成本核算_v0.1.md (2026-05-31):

# SYS-BOM-001 整机BOM成本核算 v0.1

**项目**: EL-1000 1000W 可编程直流电子负载  
**版本**: v0.1  
**日期**: 2026-05-31  
**状态**: 初稿

---

## 1. 概述

本文档汇总 EL-1000 整机物料清单 (BOM) 成本核算。基于前期分模块 BOM 汇总，补充机箱、连接器、PCB、组装、包装及配件等缺失项，形成完整整机成本基线。

**核算前提**:
- 数量: 小批量 50–200 台
- 单价: 以 LCSC / 淘宝 / 1688 批量价为准
- 币种: 人民币 (¥)
- 不含税、不含模具摊销
- 不含运费、关税

---

## 2. 现有分模块 BOM 成本（来自硬件设计文档）

### 2.1 功率级 BOM — ~¥238

| 项目 | 物料 | 数量 | 小计 (¥) | 来源 |
|---|---|---|---|---|
| MOSFET | M90N20 (200V/90A TO-247) | 12 | 120 | 迈诺斯(台产/国产) ¥10/颗 |
| 检流电阻 | MCSF2512DR050Q9 (0.05Ω 3W) | 12 | 29.84 | 开步睿思 ¥0.82×12×0.05Ω |
| DAC | SGM71622R2 (16-bit SPI) | 1 | — | 圣邦微(待询价) |
| ADC | ADS1115IDGSR (16-bit ΔΣ I2C) | 1 | 8.30 | TI |
| 运放 | LM358 (MSKSEMI) | 1 | 0.24 | 美森科 |
| 推挽驱动 | D882 + B772 TO-126 | 4 | 1.60 | 国产 |
| 栅极下拉 | N7002N (60V SOT-23) | 2 | 0.60 | 国产 |
| 分压/偏置阻容 | 0805 电阻 × 56 + 电容 × 20 | — | 10.00 | 国产 |
| 绝缘垫 | AlN 氮化铝 TO-247 | 12 | 36.00 | 国产 |
| PCB | 4层 2oz 铜 (功率级) | 1 | 30.00 | 含打样费摊销 |
| **小计** | *(不含 DAC)* | | **~238** | DAC 待补 ~¥15–25 |

> *功率级 BOM 中 DAC 暂估 ¥20，则功率级完整成本约 **¥258**。为保守起见采用 ¥238。*

### 2.2 控制电路 BOM — ~¥196

| 物料类 | 估测依据 | 估测金额 (¥) |
|---|---|---|
| C2000 F28E12x | ¥60-80 (TI) | 70 |
| 晶振/时钟 | 25MHz + RTC 32.768kHz | 5 |
| 隔离器件 | ISO77xx / 分立光耦 × 4 | 12 |
| 隔离电源 | B0505 × 2 + B1515 | 25 |
| 信号调理 | 运放 + 精密电阻 + 保护 | 15 |
| 通信接口 | CAN (SN65HVD230) + UART-USB (CH340) + WiFi | 20 |
| ESP32-S3-WROOM-1 | WiFi/BLE 模块 | 25 |
| OLED 显示模块 | 128×64 I2C | 12 |
| 按键/旋钮 | 编码器 + 按键 × 4 | 8 |
| PCB | 4层板 80×100mm | 15 |
| 杂项 | 阻容 + 接插件 | 14 |
| **小计** | | **~196** |

### 2.3 电源树 BOM — ~¥148

| 物料类 | 估测依据 | 估测金额 (¥) |
|---|---|---|
| 开关电源模块 | 48V→±15V/12V/5V 多路输出 | 45 |
| LDO 稳压器 | 3.3V/1.8V/1.2V LDO × 5 | 15 |
| 辅助电源反激 | UCC28C45 + 变压器 + 反馈 | 25 |
| 输入滤波 | 保险丝 + 共模扼流圈 + X/Y 电容 | 18 |
| TVS/保护 | 输入端 TVS + 压敏电阻 | 8 |
| 电源监测 | 电压/电流监测 IC | 12 |
| 散热电源风扇 | 12V/0.5A PWM 风扇 | 20 |
| 杂项 | 储能电容 + 阻容 | 5 |
| **小计** | | **~148** |

### 2.4 安全防护 BOM — ~¥78

| 物料类 | 估测依据 | 估测金额 (¥) |
|---|---|---|
| 过流保护 | 断路器 / 保险丝座 + 保险丝 | 12 |
| 过温保护 | NTC × 3 + 比较器 | 8 |
| 紧急停止 | 急停开关 (红色蘑菇头) | 15 |
| 继电器 | 功率继电器 × 2 (输出通断) | 20 |
| ESD 保护 | TVS 阵列 × 5 | 10 |
| 隔离屏障 | 爬电距离开槽 / 绝缘挡板 | 8 |
| 接地 | 接地铜排 + 接地标识 | 5 |
| **小计** | | **~78** |

### 2.5 散热系统 BOM — ~¥216

| 物料类 | 估测依据 | 估测金额 (¥) |
|---|---|---|
| 散热器 | 挤压铝型材 300×150×50mm | 80 |
| AlN 绝缘垫 | TO-247 氮化铝绝缘片 × 12 | 36 |
| 散热风扇 | 12038 12V PWM 风扇 | 35 |
| 导热硅脂 | 信越 X-23-7762 / 国产替代 (5g) | 15 |
| 热管 (可选) | 烧结热管 × 4 (高强度方案) | 40 |
| 温度传感器 | NTC 热敏电阻 (贴片) × 3 | 6 |
| 安装配件 | 弹簧夹 / 螺丝 / 压片 | 4 |
| **小计** | | **~216** |

### 2.6 已核算分项总计

| 子模块 | 金额 (¥) |
|---|---|
| 功率级 | 238 |
| 控制电路 | 196 |
| 电源树 | 148 |
| 安全防护 | 78 |
| 散热系统 | 216 |
| **子总计** | **¥876** |

---

## 3. 补充缺失项

### 3.1 机箱/外壳 (Enclosure/Chassis) — ~¥175

| 物料 | 规格 | 小计 (¥) | 说明 |
|---|---|---|---|
| 钣金机箱 | 1.2mm SGCC 镀锌板, 约 320×260×160mm | 80–120 | 含上下盖+底板, 折弯/冲孔/喷涂 |
| 前面板 | 4mm 铝板, 拉丝氧化 (或亚克力) | 30–50 | 含丝印/激光刻字 |
| 后面板 | 2mm 镀锌板 (同机箱料) | 15 | — |
| 五金配件 | 螺丝/垫片/螺母/脚垫/把手 | 15 | — |
| **小计** | | **~175** | 批量定型后冲压模具 ¥3,000–5,000 |

### 3.2 连接器 (Connectors / I/O) — ~¥51

| 物料 | 单价 (¥) | 数量 | 小计 (¥) | 说明 |
|---|---|---|---|---|
| 接线柱 (红黑) | 12.5 | 2 | 25 | 4mm 镀金香蕉座 |
| IEC 电源插座 | 8 | 1 | 8 | 含保险丝座 + 开关 |
| 风扇连接器 | 3 | 1 | 3 | 2.54mm 4P 端子 |
| 输入接头 (XT60/Anderson) | 8 | 1 | 8 | 大电流快插 |
| 内部排线/线束 | 15 | 1 | 15 | AWG14/18 + 端子 |
| **小计** | | | **~51** | — |

### 3.3 PCB 制板 (PCB Fabrication) — ~¥75

| 板卡 | 规格 | 单价 (¥) | 说明 |
|---|---|---|---|
| 功率主板 | 100×160mm, 4层 2oz 铜 | 35 | 含 FR4 TG170, ENIG |
| 控制板 | 80×100mm, 4层 1oz 铜 | 25 | — |
| 电源板 | 60×80mm, 2层 2oz 铜 | 15 | — |
| **小计** | | **~75** | JLCPCB 打样价, 批量可降 40%+ |

### 3.4 组装 (Assembly) — ~¥130

| 工序 | 单价 (¥) | 说明 |
|---|---|---|
| SMT 贴片 (3 板 × 约 150 点) | 60 | 含钢网, 批量 50pcs 起 |
| 波峰焊 (插件) | 30 | 变压器/继电器/接线柱 |
| 人工组装 (整机) | 40 | 含测试、老化、终检 |
| **小计** | | **~130** | 含测试工时摊销 |

### 3.5 包装 (Packaging) — ~¥31

| 物料 | 单价 (¥) | 说明 |
|---|---|---|
| 彩盒 (瓦楞 + 彩印) | 15 | 4C 印刷, 白卡裱 E 瓦 |
| 珍珠棉 (EPE 内衬) | 8 | 定制模切 |
| 用户手册 | 5 | 黑白印刷, 32P |
| 气泡袋 | 3 | 防静电 |
| **小计** | | **~31** | — |

### 3.6 配件 (Accessories) — ~¥16

| 物料 | 单价 (¥) | 说明 |
|---|---|---|
| USB 数据线 (Type-C) | 5 | 1m |
| 电源线 (国标/欧标/美标) | 8 | 按目标市场 |
| 出厂校准报告 | 3 | 含校准数据 |
| **小计** | | **~16** | — |

---

## 4. 整机 BOM 汇总

### 4.1 总成本

| 成本项 | 金额 (¥) | 占比 |
|---|---|---|
| **电子物料 (子总计)** | **876** | 64.7% |
| 功率级 | 238 | 17.6% |
| 控制电路 | 196 | 14.5% |
| 电源树 | 148 | 10.9% |
| 安全防护 | 78 | 5.8% |
| 散热系统 | 216 | 15.9% |
| **补充项** | **478** | **35.3%** |
| 机箱/外壳 | 175 | 12.9% |
| 连接器 | 51 | 3.8% |
| PCB 制板 | 75 | 5.5% |
| 组装 | 130 | 9.6% |
| 包装 | 31 | 2.3% |
| 配件 | 16 | 1.2% |
| **整机 BOM 总计** | **¥1,354** | **100%** |

### 4.2 成本占比分析

```
成本结构分布 (¥1,354)

功率级        238  ██████████████▋         17.6%
控制电路      196  ███████████▊            14.5%
电源树        148  █████████                10.9%
安全防护       78  █████                     5.8%
散热系统      216  █████████████▍           15.9%
机箱/外壳     175  ███████████              12.9%
连接器         51  ███▌                      3.8%
PCB 制板       75  █████                     5.5%
组装          130  ████████▏                 9.6%
包装           31  ██                        2.3%
配件           16  █                         1.2%
              ─────
             ¥1,354
```

### 4.3 与零售价对比

| 项目 | 金额 (¥) |
|---|---|
| **整机 BOM 成本** | **¥1,354** |
| 目标零售价 (最低) | ¥3,999 |
| 目标零售价 (最高) | ¥5,999 |
| 毛利率 (含 BOM 成本) | 66%–77% |
| 建议渠道价 (批发 60%零售) | ¥2,399–3,599 |
| 渠道毛利率 | 44%–62% |

> **结论**: BOM 成本 ¥1,354 在 ¥3,999–5,999 零售价区间内毛利空间充裕。考虑运营、售后、认证、模具分摊后，预计整体毛利率仍可维持 **40%–55%**。

---

## 5. BOM 降本方向

| 降本项 | 当前成本 (¥) | 优化后 (¥) | 节省 (¥) | 风险/备注 |
|---|---|---|---|---|
| M90N20 批量价 (500+) | 120 (12×¥10) | 96 (12×¥8) | 24 | 需与 MINOS 谈代理价 |
| 散热器 挤压改型材优化 | 80 | 55 | 25 | 减少加工余量 |
| 机箱 冲压模具分摊 | 175 (单台) | 90 (200台分摊后) | 85 | 需模具 ¥4,000 分摊 |
| PCB 批量 4层板 | 75 | 40 | 35 | 批量 500+ 单价降 40% |
| SMT 批量拼板 | 60 | 25 | 35 | 拼板减少换线费 |
| 包装彩盒 批量 | 15 | 8 | 7 | 1000+ 批量价 |
| **批量 200 台后合计** | | | **~¥211** | 整机 BOM 可降至 **¥1,143** |
| **批量 500 台后合计** | | | **~¥300** | 整机 BOM 可降至 **¥1,054** |

---

## 6. 风险 & 注意事项

1. **DAC 价格待确认** — SGM71622R2 (圣邦微) 尚未获得正式报价，暂估 ¥15–25/颗
2. **C2000 F28E12x 供应风险** — TI 芯片近期周期较长 (8–12 周)，需提前下单锁定
3. **AlN 垫片备选** — 若氮化铝垫片成本过高，可考虑 氧化铝 (Al₂O₃) 或 导热硅胶垫片 (TGP)，成本从 ¥36 降至 ¥12–18，但热阻增加 0.3–0.5°C/W
4. **运费未计入** — 各芯片运费分摊约 ¥5–10/台 (多供应商)
5. **不良率预留** — 生产不良率 3%–5%，约 ¥40–68/台 隐形成本
6. **价格波动** — 功率 MOSFET (M90N20) 价格受原材料 (硅/铜) 价格波动影响

---

**版本历史**

| 版本 | 日期 | 变更内容 | 编制人 |
|---|---|---|---|
| v0.1 | 2026-05-31 | 初稿 — 基于模块 BOM 汇总 + 补充项核算 | — |

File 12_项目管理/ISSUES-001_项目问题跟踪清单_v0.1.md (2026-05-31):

# 项目问题跟踪清单 (Issue Tracker)
## EL-1000 1000W可编程直流电子负载
> 基于 Codex 评估 + 人工复核 | 2026-05-31 | W7

---

## 已修复 🔧 (本会话已完成)

| # | 问题 | 严重度 | 修复内容 |
|---|---|---|---|
| 1 | 功率级原理图工作树被清空 | 🔴 | git checkout HEAD 恢复（1648行KiCad 8格式） |
| 2 | 控制电路KiCad原理图—只有设计说明无落地文件 | 🔴 | EL-1000_ControlCircuit.kicad_sch (57KB, 92元件) |
| 3 | 电源树KiCad原理图—只有设计说明无落地文件 | 🔴 | EL-1000_PowerTree.kicad_sch (60KB, 65元件) |
| 4 | 06_软件研发目录完全空 | 🔴 | 固件骨架: 39文件 (C2000+ESP32双MCU) |
| 5 | 控制算法缺少设计文档和仿真验证 | 🔴 | SYS-CTRL-001 设计文档 + pid_sim.py + 5张分析图 |
| 6 | 安规认证路径不清晰 | 🟠 | SYS-QA-001 安规认证策略文档(CE/FCC/UL) |
| 7 | BOM成本低估(缺外壳/接插件/线束/包装) | 🟠 | SYS-BOM-001 整机BOM核算: ¥1,354 |
| 8 | 供应链调研缺失 | 🟠 | SYS-SUP-001 供应链摸底框架文档 |
| 9 | 缺乏快速原型验证策略 | 🟡 | SYS-TEST-001 3阶段原型验证计划 |
| 10 | .gitignore未排除~$临时文件 | 🟡 | 已优化，添加二进制文件管理建议 |

---

## 遗留问题 (等待后续会话)

### 🔴 严重

| # | 问题 | 说明 | 建议优先级 |
|---|---|---|---|
| P1 | **PCB Layout还没开始** | 功率级PCB布局是项目关键路径。寄生参数、热管理、Kelvin采样走线非常关键 | W9-W12 |
| P2 | **24周开发周期过于激进** | 同类产品开发12-18个月。6个月原型验证可行，但量产发布可能需延期 | W12前评估 |
| P3 | **元器件的KiCad封装库尚未分配** | 原理图的符号没有对应的Footprint封装，无法进入PCB Layout阶段 | W8-W9 |
| P4 | **KiCad版本兼容性** | 原理图使用KiCad 8格式(20230121)，WSL环境安装的是KiCad 7。需在Windows KiCad 8中编辑 | W7 |

### 🟠 较严重

| # | 问题 | 说明 | 建议优先级 |
|---|---|---|---|
| P5 | **C2000 F28E12x供货风险** | TI芯片交期8-12周，需提前下单。备选STM32G4方案需评估 | W7下单 |
| P6 | **DAC SGM71622R2价格未知** | 设计说明中价格标注"待查"，影响BOM准确性 | W7 |
| P7 | **控制电路原理图需要在KiCad GUI中完善连线** | 脚本生成的.sch文件只有元件放置和全局标签，精确的wire/net需在KiCad中完成 | W7-W8 |
| P8 | **ID-SPEC-001 风扇尺寸未更新** (80mm→120mm) | MTG-014已识别但未修复，影响后续结构设计 | W8 |

### 🟡 次要

| # | 问题 | 说明 |
|---|---|---|
| P9 | .docx/.pptx 二进制文件在git中占空间 | 建议用Git LFS管理，或拆分为.md版本保留在git，二进制存云盘 |
| P10 | SGM71622R2 vs GP8101 DAC方案需确认 | GP8101 (PWM转模拟 ¥2.5) 是更便宜的选择，但精度不同 |
| P11 | 缺少层次化原理图设计 | 当前3张原理图（功率级/控制电路/电源树）建议建立顶层图纸 |
| P12 | 软件目录中缺少4个文件 | protocol.c/wifi.h/wifi.c/data_log.c 因迭代限制未完成 |

---

## 建议的下一步工作顺序

```
W7 (当前)
├── [立即] 在Windows KiCad 8中打开并完善控制电路原理图连线
├── [立即] 在Windows KiCad 8中打开并完善电源树原理图连线
├── [高优] 为所有元件分配Footprint封装
├── [高优] 确认SGM71622R2价格或切换到GP8101方案
├── [高优] 下单C2000 F28E12x + ESP32-S3-WROOM-1样品
└── [进行] 完成固件骨架中缺失的4个文件

W8-W9
├── 建立层次化原理图 (顶层图纸关联3张子图)
├── 启动功率级PCB布局 (关键路径)
├── Phase 1原型验证: C2000 LaunchPad + 单管M90N20
├── ID-SPEC-001 风扇尺寸更新 (80→120mm)
└── .docx/.pptx 迁移策略 (LFS或云盘)

W10-W12
├── 控制电路+电源树PCB布局
├── Gerber文件生成 → JLCPCB打样
├── Phase 2: 4管验证平台
├── 供应链: 量产BOM + 供应商比价
└── 安规预测试 (EMI设计review)

W12-W14
├── Phase 3: 完整12管原型
├── 整机联调 (硬件+固件)
└── W14: 原型验收
```

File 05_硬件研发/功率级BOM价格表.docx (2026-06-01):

# EL-1000 功率级 BOM

原型阶段 (小批量) 价格 | 数量按12管/1台计 | 2026-05-29

# | 位号 | 物料 | 规格 | 封装 | 数量 | 单价(¥) | 小计(¥) | 品牌 | 备注

1 | Q1-Q12 | M90N20 | 200V/90A TO-247 | TO-247 | 12 | 10 | 120 | MINOS(迈诺斯) | PD=580W, Rth=0.29°C/W
2 | RS1-12 | MCSF2512DR050Q9 | 0.05Ω ±0.5% 3W | 2512 | 12 | 0.82 | 9.84 | 开步睿思(RESI) | 4端开尔文
3 | U_D | SGM71622R2 | 双16-bit SPI DAC | TQFN-3×3 | 1 | — | — | 圣邦微(SGM) | ⚠️ 价格待查
4 | U_A | ADS1115IDGSR | 16-bit ΔΣ ADC I2C | VSSOP-10 | 1 | 8.30 | 8.30 | TI | 860SPS, 4ch
5 | U_L | LM358 (MSKSEMI) | 双运放 | SOP-8 | 1 | 0.24 | 0.24 | 美森科
6 | Q_D1-2 | D882 | NPN 3A TO-126 | TO-126 | 2 | 0.40 | 0.80 | 国产 | 推挽上管
7 | Q_D3-4 | B772 | PNP -3A TO-126 | TO-126 | 2 | 0.40 | 0.80 | 国产 | 推挽下管
8 | Q_PD | 2N7002 | N-MOS 60V SOT-23 | SOT-23 | 2 | 0.30 | 0.60 | 国产 | 栅极快速下拉
9 | U_DIV | 分压电阻 | 95kΩ+5.23kΩ 1% | 0805 | 2 | 0.10 | 0.20 | | DAC→LM358分压
10 | RG1-12 | 栅极电阻 | 10Ω ±1% | 0805 | 12 | 0.10 | 1.20 | | 防振荡
11 | RGS1-12 | 栅极下拉 | 10kΩ ±1% | 0805 | 12 | 0.10 | 1.20 | | 上电关断
12 | R_sum | 求和电阻 | 10kΩ ±1% | 0805 | 12 | 0.10 | 1.20 | | 源极V端求和
13 | R_base | 基极限流 | 220Ω ±1% | 0805 | 4 | 0.10 | 0.40 | | LM358→推挽基极
14 | — | 绝缘垫 | AlN TO-247 氮化铝 | TO-247 | 12 | 3.00 | 36.00 | 国产 | Rth=0.15°C/W
15 | — | 阻容杂项 | 0805/1206/通孔 | — | — | — | 10.00 | | 退耦/滤波/偏置
16 | — | PCB | 4层板 2oz 铜 | — | 1 | 30.00 | 30.00 | | 含打样费摊销
| | 合计 (不含DAC) | | | | | ~¥221 | | 功率级
| | DAC待补 | SGM71622R2 | | 1 | 待查 | 待查

价格说明:

• 以上为1台原型样机BOM, 小批量(50+)价格更低
• M90N20 按 ¥10/颗 估价 (Taobao/立创, 待采购确认)
• MCSF2512DR050Q9 按 50+批量 ¥0.82 (立创现货1220颗)
• PCB按30元/片估算, 批量<¥10/片
• 不含SGM71622R2价格 (待圣邦微确认)
• 不含功率级连接器、铜排、焊锡、三防漆等辅材
• 不含散热器 (计入散热BOM ¥216)

成本分布:

物料 | 金额(¥) | 占比
M90N20 ×12 | 120 | ~54%
AlN陶瓷垫 ×12 | 36 | ~16%
MCSF2512DR050Q9 ×12 | 9.84 | ~4%
PCB | 30 | ~14%
ADS1115 | 8.30 | ~4%
其余 (驱动+采样+保护) | 16.64 | ~8%
合计 (不含DAC) | ~221 | 100%
SGM71622R2 (待补) | 待查 | —

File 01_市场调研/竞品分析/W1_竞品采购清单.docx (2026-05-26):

# 1000W 直流电子负载 — 竞品采购清单

文档编号: MR-001 | 版本: v1.0 | 日期: 2026-05-26 | 负责人: AI产出 / 用户执行采购

# 一、推荐采购竞品

以下3款为1000W级别最具代表性的竞品，分别覆盖高中低三个价位段。建议全部采购进行拆解对标。

型号 | 品牌 | 规格 | 参考价格 | 定位 | 采购理由
IT8512+ | 艾德克斯 ITECH | 1200W / 150V / 30A | ¥3,500-5,000 | 中端标杆 | 国产中高端，市场占有率高，是直接竞争对标对象。重点关注：精度、散热方案、面板UI、上位机软件。
M9713 | 美尔诺 Maynuo | 1200W / 150V / 60A | ¥1,500-2,500 | 性价比标杆 | 国产性价比之王，DIY社区常用。重点关注：与ITECH的性能差距、成本控制手段、结构做工。
8602 | BK Precision | 1200W / 500V / 240A | $1,800-2,500 | 海外中端标杆 | 北美市场主流中端型号。重点关注：安规设计、EMC处理、软件国际化、售价与BOM的关系。

# 二、采购渠道建议

型号 | 推荐渠道 | 搜索关键词 | 注意事项
IT8512+ | 淘宝/京东 | 搜索"IT8512+ 电子负载" | 选择企业店铺或授权经销商，注意索要发票和校准证书
M9713 | 淘宝 | 搜索"M9713 电子负载 美尔诺" | 价格区间大，选择成交量高的店铺，确认是否含校准
8602 | Amazon / Digi-Key | 搜索"BK Precision 8602" | 注意110V/220V版本选择；或通过得捷电子(Mouser)订购免运费

# 三、拆解分析维度

竞品到货后，请按以下维度逐项分析记录（拍照+笔记）。AI 将在 W2 输出拆解分析模板。

分析维度 | 方法/工具 | 关注要点
性能标定 | 使用6½位万用表+示波器 | 设定精度、回读精度、纹波噪声、动态响应时间、负载调整率
功率拓扑 | 拆机拍照+器件识别 | MOSFET型号/数量、驱动方式、散热器规格/重量、风扇型号/风量
硬件设计 | PCB拍照+芯片识别 | 主控MCU型号、ADC型号/位数、隔离方案、电源设计、PCB层数
结构工艺 | 外观+内部拍照 | 外壳材质/工艺、面板布局、接线柱质量、装配精度、风道设计
软件体验 | 实际操作+录屏 | 上位机UI/UX、通信协议支持、响应速度、功能完整度、Bug
成本估算 | BOM反推 | 根据拆解结果估算BOM成本（IC+MOSFET+PCB+结构+电源+包装）
用户评价 | 电商+论坛收集 | 淘宝/Amazon评价、EEVblog讨论、知乎/B站评测、常见投诉点

# 四、采购预算

型号 | 单价（含税） | 小计
IT8512+ | ¥4,500 | ¥4,500
M9713 | ¥2,000 | ¥2,000
8602 (BK Precision) | $2,100 (≈¥15,000) | ¥15,000
合计 | | ≈ ¥21,500

☐ 用户操作：确认预算 → 下单采购 → 预计到货时间: ___天

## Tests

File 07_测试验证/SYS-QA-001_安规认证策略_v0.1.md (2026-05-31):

# SYS-QA-001 安规认证策略 v0.1

**项目**: EL-1000 1000W 可编程直流电子负载  
**版本**: v0.1  
**日期**: 2026-05-31  
**状态**: 初稿

---

## 1. 适用标准

EL-1000 为可编程直流电子负载，归类为 **实验室电气设备 / 测量、控制和实验室用电气设备**，主要适用标准如下：

### 1.1 安全标准

| 标准 / 法规 | 适用区域 | 说明 |
|---|---|---|
| **IEC 61010-1** | 国际 | 测量、控制和实验室用电气设备的安全要求 — 第1部分：通用要求 |
| **EN 61010-1** | 欧盟 | IEC 61010-1 的欧盟采纳版，CE 标志核心安全标准 |
| **UL 61010-1** | 美国/北美 | UL 采纳版，与 IEC 61010-1 技术等同，但 NRTL 认证需 UL 版本 |
| **GB 4793.1** | 中国 | 对应 IEC 61010-1 的国标，CCC 认证基础标准 |

> EL-1000 工作电压 **< 600V DC**，额定功率 **1000W**，属于 **I 类测量设备**（CAT I / II 环境），适用过电压类别 II，污染等级 2。

### 1.2 EMC 标准

| 标准 / 法规 | 适用区域 | 说明 |
|---|---|---|
| **EN 55032 (CISPR 32)** | 欧盟 | 多媒体设备辐射 & 传导发射限值 |
| **EN 55035 (CISPR 35)** | 欧盟 | 多媒体设备抗扰度要求 |
| **EN 61000-3-2** | 欧盟 | 谐波电流发射限值（≤16A/相） |
| **EN 61000-3-3** | 欧盟 | 电压波动和闪烁限值 |
| **FCC Part 15 Subpart B** | 美国 | 无意辐射体发射限值（Class A / Class B） |
| **GB/T 9254.1** | 中国 | 对应 EN 55032 的国标 |

### 1.3 环保 / 能效

| 标准 / 法规 | 适用区域 | 说明 |
|---|---|---|
| **RoHS (EU 2015/863)** | 欧盟 | 有害物质限制（10项） |
| **WEEE (EU 2012/19)** | 欧盟 | 废弃电气电子设备指令 |
| **REACH (EU 1907/2006)** | 欧盟 | 化学品注册、评估、授权与限制 |
| **China RoHS (GB/T 26572)** | 中国 | 电子电器产品有害物质限制 |

---

## 2. 认证路线选择

### 2.1 策略建议

| 目标市场 | 认证方案 | 预计费用 (¥) | 周期 | 说明 |
|---|---|---|---|---|
| **欧盟 (EU)** | **CE (EMC + LVD)** | 40,000–70,000 | 2–3 个月 | 自声明 (DoC) + 技术文档 + 测试报告 |
| **美国 (USA)** | **FCC SDoC** | 20,000–40,000 | 1–2 个月 | 供应商符合性声明，无需 FCC 发证 |
| **美国 (USA)** | **FCC + NRTL (UL)** | 80,000–150,000 | 4–6 个月 | 需 UL 授权 NRTL 测试，费用较高 |
| **中国 (CN)** | **CCC 自愿认证** | 30,000–50,000 | 3–4 个月 | 非强制性，但渠道商可能要求 |
| **全球通用** | **CB 报告** | 30,000–50,000 | 3–4 个月 | IECEE CB 体系，一国测试多国认可 |

### 2.2 推荐路线（按阶段）

#### 阶段一：原型验证 → 小批量（首批 50–200 台）
- **CE 自声明** (EMC + LVD)：内部预扫 + 第三方 EMC 预测试
- **FCC SDoC**：自行测试并出具报告
- **RoHS / REACH 合规声明**
- **目标费用**: ~¥30,000–50,000（预测试 + 报告编制）

#### 阶段二：量产（批次 >500 台/年）
- **CE 全项认证** + **FCC 正式测试** + **CB 报告**（覆盖全球）
- **考虑 UL 认证**（北美渠道要求时启动）
- **目标费用**: ~¥80,000–150,000

---

## 3. 测试项目清单

### 3.1 安规测试 (IEC/EN 61010-1)

| 测试项目 | 判定标准 | 设备需求 | 预计费用 |
|---|---|---|---|
| 接地连续性 | ≤0.1Ω（接地回路） | 接地电阻测试仪 | 自测 |
| 绝缘耐压 (Hi-Pot) | 交流 1500V / 1min, 漏电流 ≤5mA | 耐压测试仪 | 自测 |
| 绝缘电阻 | ≥2MΩ (500V DC) | 绝缘电阻表 (兆欧表) | 自测 |
| 爬电距离 / 电气间隙 | ≥3mm (基本绝缘, 300V) | 卡尺 + 目检 | 自测 |
| 漏电流 | ≤0.5mA (接触电流) | 漏电流测试仪 | 自测 |
| 异常条件 / 单一故障 | 无火灾、电击风险 | — | 自测 |
| 球压试验 (塑料外壳) | ≥75°C (125°C) | 球压测试仪 | 外协 |

### 3.2 EMC 发射测试 (EN 55032 / FCC Part 15)

| 测试项目 | 频率范围 | 限值 | 是否预扫 | 正式费用 |
|---|---|---|---|---|
| 传导发射 (CE) | 150 kHz – 30 MHz | Class A / Class B | ✓ | ¥3,000–5,000 |
| 辐射发射 (RE) | 30 MHz – 1 GHz (向上至 6 GHz) | Class A / Class B | ✓ | ¥5,000–8,000 |

### 3.3 EMC 抗扰度测试 (EN 55035)

| 测试项目 | 标准 | 严酷等级 | 正式费用 |
|---|---|---|---|
| 静电放电 (ESD) | IEC 61000-4-2 | ±4 kV 接触 / ±8 kV 空气 | ¥2,000–4,000 |
| 射频电磁场 | IEC 61000-4-3 | 3 V/m, 80 MHz – 6 GHz | ¥3,000–5,000 |
| 电快速瞬变脉冲群 (EFT) | IEC 61000-4-4 | ±1 kV (电源端口) | ¥2,000–4,000 |
| 浪涌 (Surge) | IEC 61000-4-5 | ±1 kV / ±2 kV (线-线/线-地) | ¥2,000–4,000 |
| 射频传导抗扰度 | IEC 61000-4-6 | 3 V, 150 kHz – 80 MHz | ¥2,000–4,000 |
| 工频磁场 | IEC 61000-4-8 | 50/60 Hz, 30 A/m | ¥1,500–3,000 |
| 电压暂降 / 中断 | IEC 61000-4-11 | 0%/40%/70% 电压暂降 | ¥1,500–3,000 |

### 3.4 其他测试

| 测试项目 | 标准 | 说明 |
|---|---|---|
| 谐波电流 | EN 61000-3-2 | P≤75W 豁免？EL-1000 需确认功耗 |
| 电压闪烁 | EN 61000-3-3 | 主要关注大功率瞬态切换 |
| RoHS 分析 | IEC 62321 | 需送样至 SGS / TÜV / CTI |

---

## 4. 时间线估计

```
原型 → 预扫 → 整改 → 正式测试 → 发证

W1-W4      W5-W6      W7-W10    W11-W14    W15-W16
  |          |           |          |          |
┌──────┐  ┌──────┐  ┌────────┐  ┌──────┐  ┌──────┐
│PCB+  │→ │EMC预 │→ │EMC整改 │→ │正式  │→ │CE/FCC│
│样机  │  │扫    │  │+安全测试│  │测试  │  │发证  │
└──────┘  └──────┘  └────────┘  └──────┘  └──────┘
```

### 4.1 乐观时间线（无重大整改）
- **原型 + 自测**: 4 周
- **EMC 预测试 + 整改**: 2–4 周
- **正式测试**: 2–4 周
- **报告 + 发证**: 2–4 周
- **合计**: **10–16 周 (2.5–4 个月)**

### 4.2 保守时间线（含多轮整改）
- **合计**: **4–6 个月**

---

## 5. 费用预算

### 5.1 最低方案 (CE 自声明 + FCC SDoC)

| 项目 | 费用 (¥) |
|---|---|
| EMC 预测试 (传导 + 辐射) | 3,000–5,000 |
| EMC 正式测试 (传导 + 辐射) | 8,000–12,000 |
| 抗扰度正式测试 (ESD + EFT + Surge) | 6,000–10,000 |
| 安全测试 (自测 + 第三方见证) | 5,000–10,000 |
| 技术文档 + DoC 编制 | 3,000–5,000 |
| RoHS 分析报告 | 2,000–3,000 |
| **合计** | **¥27,000–45,000** |

### 5.2 完整方案 (CE 全项 + FCC + CB)

| 项目 | 费用 (¥) |
|---|---|
| EMC 全项 (发射 + 抗扰度 7项) | 25,000–40,000 |
| LVD 安全全项 (IEC 61010-1) | 15,000–25,000 |
| FCC Part 15 正式测试 | 10,000–20,000 |
| CB 测试报告 | 20,000–35,000 |
| RoHS / REACH 分析 | 3,000–5,000 |
| 技术文档 + 代理人 | 5,000–10,000 |
| 整改 / 复测预留 | 10,000–20,000 |
| **合计** | **¥88,000–155,000** |

---

## 6. 风险缓解策略

### 6.1 设计阶段 EMC 防护

| ✅ 必做项 | 说明 |
|---|---|
| **PCB 4 层板设计** | 完整地平面，降低回路电感 |
| **输入 EMI 滤波器** | 共模扼流圈 + X/Y 电容，预留 π 型滤波位置 |
| **栅极驱动回路最小化** | 驱动走线<10mm，推挽紧贴 MOSFET |
| **功率回路与信号回路隔离** | 功率地-信号地单点连接，星形接地 |
| **MOSFET 开关边沿缓控** | 栅极电阻 10Ω，控制 di/dt、dv/dt |
| **C2000 PWM 输出 RC 滤波** | 每个 PWM 输出串联 33Ω + 100pF 对地 |
| **风扇 PWM 调速滤波** | 风扇线缆屏蔽 + 磁珠滤波 |
| **输入端口保护** | TVS + 共模扼流圈 + 放电管 |
| **屏蔽设计预留** | 外壳密封导电衬垫位置预留 |
| **Layout 评审检查项** | 重点检查高速信号回路面积、晶振/时钟走线 |

### 6.2 安全设计

| ✅ 必做项 | 说明 |
|---|---|
| **保险丝 / 断路器** | 输入回路 - 变压器原边保险，功率级硬件 OCP |
| **输入/输出隔离** | 控制回路与功率回路通过隔离电源 + 数字隔离器 |
| **紧急关断 (E-Stop)** | 硬件独立关闭 MOSFET 栅极驱动 |
| **温度保护** | NTC 多点监测 + 固件 OTP + 硬件 OTP 冗余 |
| **外壳防护** | 接地端子 + 金属外壳接地 + 防手指触碰 |
| **爬电距离** | 确保初级-次级间 ≥5.5mm (双重绝缘) |
| **所有高压区域标示** | 警告标签 ≥ 高压 50V 区域 |

### 6.3 预扫安排

| 阶段 | 动作 | 供应商 |
|---|---|---|
| PCB 投板前 | 关键信号 SI/PI 仿真 (可选) | 内部 / Altium 仿真 |
| 第一版样机 (W6) | EMC 传导 + 辐射预扫 | 华测检测 (CTI) / 莱茵 (TÜV) |
| 整改后复测 (W8) | 传导 + 辐射验证预扫 | 同上 |
| 正式测试前 (W10) | 全项预扫 (ESD / EFT / Surge) | 同上 |

### 6.4 认证策略决策树

```
是否出口欧盟？
 ├─ 是 → 是否需要 CE 全项？
 │       ├─ 是 → 委托 TÜV/SGS 全项测试 + 技术文档
 │       └─ 否 → 自声明 DoC + 预测试报告
 ├─ 否 → 是否出口美国？
 │       ├─ 是 → FCC SDoC + 考虑 NRTL (UL)
 │       └─ 否 → 是否需要 CB 报告（全球覆盖）？
 │               ├─ 是 → CB 测试 + 转国家差异
 │               └─ 否 → 仅 RoHS 合规声明
```

---

## 7. 推荐认证合作实验室

| 实验室 | 优势 | 地点 | 参考报价 |
|---|---|---|---|
| **SGS** | 全球认可，CE/FCC/CB 一站式 | 上海/广州/深圳 | ¥100k+ |
| **TÜV Rheinland** | CE/FCC/CB/NRTL | 深圳/上海 | ¥100k–150k |
| **华测检测 (CTI)** | 性价比高，预扫快速 | 深圳 | ¥30k–60k |
| **信测 (EMTEK)** | EMC 专业，周期短 | 深圳 | ¥30k–50k |
| **摩尔实验室 (MORLAB)** | 本地化服务，预扫优惠 | 深圳 | ¥20k–40k |

> **建议**: 预扫选择 **CTI 或信测**（性价比导向），正式 CE/FCC 测试可选 **TÜV / SGS**（权威性考虑），CB 报告推荐 **TÜV**。

---

## 8. 文档清单

| 文档 | 用途 | 责任人 |
|---|---|---|
| 技术构造文件 (TCF) | 证明符合标准的完整技术文档 | PM + 硬件 |
| 电路图 & PCB Layout | 安全分析基础 | 硬件 |
| 关键元器件清单 | 安全认证元器件（保险丝、隔离器等） | 硬件 |
| 风险管理文件 (ISO 14971 适用于医疗) | 风险分析 + 缓解措施 | PM |
| 使用说明书 (安全相关部分) | 用户安全警告 | PM + 文档 |
| 标签 / 标识 | CE / FCC / 警告标签 | 结构 + PM |
| RoHS / REACH 合规声明 | 环保合规 | PM |
| EMC 测试报告 | 证明符合发射/抗扰度限值 | 委托实验室 |
| LVD/安全测试报告 | 证明符合安全要求 | 委托实验室 |
| 符合性声明 (DoC) | 最终 CE 标志文件 | PM |

---

## 9. 附录：CE 标志流程

```
1. 确定适用指令 (EMC + LVD)
2. 确定适用协调标准
3. 准备技术文档 (TCF)
4. 执行内部或委托测试
5. 编制符合性声明 (DoC)
6. 加贴 CE 标志
7. 保留技术文档备查 (至少 10 年)
8. 指定欧盟授权代表 (EEA 外制造商)
```

---

**版本历史**

| 版本 | 日期 | 变更内容 | 编制人 |
|---|---|---|---|
| v0.1 | 2026-05-31 | 初稿 | — |

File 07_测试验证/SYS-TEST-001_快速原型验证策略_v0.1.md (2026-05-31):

# SYS-TEST-001 快速原型验证策略 v0.1

**项目**: EL-1000 1000W 可编程直流电子负载  
**版本**: v0.1  
**日期**: 2026-05-31  
**状态**: 初稿

---

## 1. 概述

本文档定义 EL-1000 的三阶段快速原型验证策略，从单管验证到 12 管满功率，逐级降低技术风险。采用 C2000 LaunchPad 开发板 + 面包板/打样 PCB 的方式，在正式 PCB 投板前完成核心算法和功率级的可行性验证。

### 1.1 核心理念

```
┌─────────────────────────────────────────────────────────────┐
│                     快速迭代 · 分阶段验证                      │
│                                                             │
│   Phase 1 (W7-W8)           Phase 2 (W9-W11)     Phase 3    │
│   ┌───────────────┐      ┌───────────────┐    ┌───────────┐│
│   │ 单管 · 面包板  │ ──→ │ 4管 · 验证板   │ ──→│ 12管 · 整机││
│   │  100W  max     │      │  400W  max     │    │ 1000W max ││
│   │  HRPWM + ADC   │      │ 均流+热分布    │    │ 全面测试  ││
│   └───────────────┘      └───────────────┘    └───────────┘│
│       2 周                   3 周                  3 周     │
│                                                             │
│   Total: 8 周 (W7-W14)                                      │
└─────────────────────────────────────────────────────────────┘
```

### 1.2 决策门 (Phase Gate)

| Phase | Exit Criteria (通过条件) | 失败回退策略 |
|---|---|---|
| Phase 1 → Phase 2 | HRPWM 输出正常, ADC 采样精度 <1%, PID 闭环稳定 | 排查 HRPWM 配置/ADC 噪声 |
| Phase 2 → Phase 3 | 4 管均流误差 <10%, 散热温差 <15°C, 无开关震荡 | 优化栅极驱动/均流电阻 |
| Phase 3 → 定型 | 1000W 满载稳定, 效率合格, 无热失控 | 调整散热/保护配置 |

---

## 2. Phase 1: 单管验证 (W7–W8)

### 2.1 目标

在 C2000 LaunchPad + 面包板上搭建 **单路 M90N20** 电子负载核心回路，验证：
- ✅ HRPWM 输出 100kHz–1MHz 可调
- ✅ ADC 高速采样 (≥20kSPS)
- ✅ PID 闭环恒流/恒压控制
- ✅ 读取并校准时序

### 2.2 硬件搭建

```
                     ┌─────────────────────────────────────┐
                     │         C2000 LaunchPad              │
                     │  (LAUNCHXL-F28E12x / F280013x)       │
                     │                                      │
                     │  GPIO0 ─→ (HRPWM) ─────────────┐    │
                     │  ADCIN0 ←─ (电流反馈) ←──┐     │    │
                     │  ADCIN1 ←─ (电压反馈) ←──┤     │    │
                     └──────────────────────────┼─────┘────┘
                                                │     │
                     ┌──────────────────────────┴─────┴─────┐
                     │       面包板 功率回路                  │
                     │    ┌──────────────┐    ┌──────────┐   │
                     │    │ 推挽驱动     │←───│ HRPWM    │   │
                     │    │ (D882+B772)  │    │ (10Ω Rg) │   │
                     │    └──────┬───────┘    └──────────┘   │
                     │           │                             │
                     │    ┌──────┴───────┐                    │
                     │    │  M90N20 × 1  │←── DUT+ (输入)     │
                     │    │  (TO-247)    │──→ DUT- (返回)     │
                     │    └──────┬───────┘                    │
                     │           │                             │
                     │    ┌──────┴───────┐                    │
                     │    │ 检流电阻 50mΩ │──→ INA/ADC         │
                     │    └──────────────┘                    │
                     └────────────────────────────────────────┘
```

### 2.3 物料清单 (Phase 1)

| 物料 | 数量 | 用途 | 来源 |
|---|---|---|---|
| LAUNCHXL-F28E12x (或 F280013x) | 1 | 控制核心 | Mouser/Digikey ~¥300 |
| 面包板 (830 孔) | 1 | 搭建平台 | 淘宝 ¥10 |
| M90N20 TO-247 | 2 | 1 用 + 1 备件 | LCSC ¥10 |
| D882 TO-126 | 2 | 推挽上管 | LCSC ¥0.4 |
| B772 TO-126 | 2 | 推挽下管 | LCSC ¥0.4 |
| N7002N SOT-23 | 5 | 栅极下拉/保护 | LCSC ¥0.3 |
| MCSF2512DR050Q9 | 2 | 检流电阻 | LCSC ¥1.64 |
| 电阻 0805 (10Ω/10kΩ/220Ω 等) | 30 | 偏置/限流 | LCSC ¥3 |
| 电容 0805/1206 | 20 | 去耦/滤波 | LCSC ¥2 |
| 铝电解 100μF/450V | 2 | 输入去耦 | LCSC ¥6 |
| TO-247 散热器 (小型) | 1 | 单管散热 | LCSC ¥8 |
| 绝缘垫 + 导热硅脂 | 1 | 安装 | LCSC ¥5 |
| 杜邦线/粗线 | 若干 | 飞线 | 淘宝 ¥5 |
| 直流电源 0-100V/10A | 1 | 测试电源 | 已有/租借 |
| 电子负载 (已有) | 1 | 校准用 | 已有 |
| **Phase 1 总投入** | | | **~¥350** |

### 2.4 测试方案

#### 2.4.1 HRPWM 输出验证

| 测试项 | 方法 | 判定标准 |
|---|---|---|
| PWM 频率 | 示波器测量 PWM 输出脚 | 设定值与实测值偏差 <1% |
| PWM 分辨率 | 逐步调整占空比 (0.1%步进) | 可分辨 <0.1% 步进变化 |
| 最小/最大占空比 | 设置 0% 和 100% | 0% 时 MOSFET 完全关断 |
| 死区时间 | 示波器查看互补 PWM (若使用) | 50–200ns 可配置 |

#### 2.4.2 ADC 采样验证

| 测试项 | 方法 | 判定标准 |
|---|---|---|
| 电流采样精度 | 串联标准电流表, 对比 ADC 读数 | 满量程误差 <1% |
| 电压采样精度 | 并联标准电压表, 对比 ADC 读数 | 满量程误差 <0.5% |
| 采样率 | GPIO 翻转法测采样周期 | ≥20kSPS (每个通道) |
| 噪声电平 | 短接 ADC 输入测量本底噪声 | 峰峰值 ≤2LSB |

#### 2.4.3 PID 闭环测试

| 测试项 | 方法 | 判定标准 |
|---|---|---|
| 恒流 (CC) 模式 | 设定 1A, 2A, 5A, 加载 10-50V | 稳定时间 <5ms, 过冲 <5% |
| 恒压 (CV) 模式 | 设定 10V, 20V, 50V, 拉载 | 稳定时间 <5ms |
| 恒功率 (CP) 模式 | 设定 10W, 20W, 50W | 功率误差 <3% |
| 恒阻 (CR) 模式 | 设定 10Ω, 50Ω, 100Ω | 电阻误差 <3% |
| 负载阶跃响应 | 1A → 5A 阶跃 | 过冲 <10%, 恢复时间 <2ms |
| 动态负载 (动态模式) | 1kHz 方波, 1A↔5A | 跟踪无振荡 |

#### 2.4.4 极限条件测试 (Phase 1 100W 上限)

| 测试项 | 条件 | 判定标准 |
|---|---|---|
| 100W 满载 | 10V × 10A / 50V × 2A | MOSFET 温度 <100°C |
| 短路保护 | 输出短路 | MOSFET 关断, 不损坏 |
| 过流保护 | 超过设定值 120% | 硬件/软件保护触发 |

### 2.5 关键风险 (Phase 1)

| 风险 | 概率 | 影响 | 缓解 |
|---|---|---|---|
| C2000 HRPWM 配置复杂 | 中 | 延迟 1 周 | 先参考 TI C2000ware 例程 |
| ADC 噪声过大影响 PID | 低 | 精度不达标 | 硬件 RC 滤波 + 软件均值滤波 |
| 面包板寄生电感导致震荡 | 高 | 波形畸变 | 缩短飞线, 功率回路尽量短 |
| PID 参数调整困难 | 中 | 闭环不稳定 | 先 Ziegler-Nichols 整定, 再 fine-tune |

---

## 3. Phase 2: 4 管验证 (W9–W11)

### 3.1 目标

在打样 PCB (2层/4层) 上搭建 **4 路 M90N20 并联** 电子负载，验证：
- ✅ 4 管电流均流 (误差 <10%)
- ✅ 热分布均匀 (温差 <15°C)
- ✅ 栅极驱动波形正常 (无振荡/串扰)
- ✅ 400W 满载稳定性
- ✅ CAN 通信正常

### 3.2 硬件搭建

**与 Phase 1 的主要差异**:
- 取消面包板，使用打样 PCB (2 层 / 4 层可选)
- 4×M90N20 共享同一散热器
- C2000 LaunchPad 通过排针接入 PCB
- 增加电流采样调理电路 (差分放大器)
- 增加 CAN 通信接口

### 3.3 PCB 快速打样

| 参数 | 值 |
|---|---|
| 层数 | 2 层 (首批) / 4 层 (可选) |
| 尺寸 | 约 100×120mm |
| 铜厚 | 2oz |
| 供应商 | JLCPCB |
| 周期 | 2–3 天 |
| 费用 | ¥30–50/片 × 5 片 = ¥150–250 |
| 发货 | JLCPCB SMT 可选 (手焊也 OK) |

### 3.4 物料增量 (Phase 2)

| 物料 | 新增数量 | 说明 |
|---|---|---|
| M90N20 | +3 (共 5) | 4 使用 + 1 备件 |
| MCSF2512DR050Q9 | +4 (共 6) | 每个 MOSFET 独立检流 |
| 推挽管 D882/B772 | 各 +3 | 独立驱动 |
| 栅极电阻/下拉 | 各 +3 | — |
| LM358 (或 INA 芯片) | 2 | 电流调理放大 (差分) |
| 大散热器 | 1 | 挤压铝型材 200×120×40mm |
| 风扇 (12V) | 1 | 4010 / 6025 小风扇 |
| CAN 收发器 | 1 | SN65HVD230 |
| PCB | 5 片 | 4 管验证板 |
| **Phase 2 追加投入** | | **~¥400–500** |

### 3.5 测试方案

| 测试项 | 方法 | 判定标准 |
|---|---|---|
| 4 管静态均流 | 在 100W-400W 各功率点, 测量每管电流 | 电流偏差 ≤10% |
| 动态均流 | 负载切换瞬间 (50%→100%) | 偏差 ≤15% |
| 栅极驱动波形 | 4 路同时测量 (示波器 4 通道) | 上升/下降 <100ns, 无振铃 |
| 热分布 | 热像仪 / 热电偶, 400W 30 分钟 | 温差 ≤15°C, 最高 <100°C |
| 交叉导通测试 | 一路先开, 延迟后开另一路 | 无瞬时短路 |
| CAN 通信 | 发送/接收 1000 帧 | 误码率 <0.1% |
| 效率/功耗 | 测量 12V 辅助电源电流 | 辅助电源功耗 <5W |
| 400W 满载稳定性 | 连续运行 1 小时, 每 5 分钟记录 | 波动 <3%, 无过热关断 |

### 3.6 关键风险 (Phase 2)

| 风险 | 概率 | 影响 | 缓解 |
|---|---|---|---|
| 4 管均流不均 | 中 | 单管过载 | 增大检流电阻精度; 软件逐周期限流 |
| 栅极串扰 (米勒效应) | 中 | 误开通/关断 | 米勒钳位电路; 增大 Rgs |
| 散热不足 | 低 | 超温 | 确认散热器热阻 <0.5°C/W |
| 回路寄生电感大 | 中 | MOSFET 尖峰电压 | 叠层母线; 吸收电容 (snubber) |

---

## 4. Phase 3: 12 管满功率原型 (W12–W14)

### 4.1 目标

在 **完整自定义 PCB** 上搭建 12 管全功能原型，达到：
- ✅ 12 管并联满功率 1000W
- ✅ 所有工作模式验证 (CC/CV/CP/CR/动态)
- ✅ 保护功能完整 (OCP/OVP/OTP/反接)
- ✅ OLED + ESP32 通信正常
- ✅ 热稳定性验证

### 4.2 硬件搭建

**与 Phase 2 的主要差异**:
- 完整 4 层 PCB (功率板+控制板 或 一体化设计)
- 12×M90N20 (3 组 × 4 管)
- 完整电源树 (反激 + LDO 多路输出)
- OLED 显示 + 旋钮/按键人机交互
- 完整保护电路 (硬件 OCP / OVP / OTP)
- 散热系统定型 (大散热器 + 12038 风扇)

### 4.3 PCB 打样

| 参数 | 值 |
|---|---|
| 层数 | 4 层 (2oz 铜内外层) |
| 尺寸 | 约 160×160mm (功率) + 80×100mm (控制) |
| 材料 | FR4 TG170, ENIG |
| 供应商 | JLCPCB / 华迅 |
| 周期 | 3–5 天 |
| 费用 | ¥50–80/片 × 10 片 = ¥500–800 |
| SMT | 嘉立创 SMT (全贴) |

### 4.4 物料增量 (Phase 3)

| 物料 | 新增数量 | 说明 |
|---|---|---|
| M90N20 | +8 (共 13) | 12 使用 + 1 备件 |
| MCSF2512DR050Q9 | +8 (共 14) | — |
| 推挽管 | 各 +8 | — |
| 电源模块 (反激) | 1 | 完整电源树 |
| ESP32-S3 模块 | 1 | WiFi 通信 |
| OLED 128×64 | 1 | 前面板显示 |
| 旋钮编码器 | 1 | 人机交互 |
| 按键 | 4 | — |
| 12038 风扇 | 1 | 散热 |
| 钣金机箱 | 1 | 原型机箱 |
| 接线柱/连接器 | 1 套 | I/O |
| PCB (功率+控制) | 1 套 | 正式版 |
| **Phase 3 追加投入** | | **~¥800–1,200** |

### 4.5 测试方案

#### 4.5.1 满载功率测试 (1000W)

| 测试项 | 条件 | 判定标准 |
|---|---|---|
| 1000W 长期稳定性 | 100V × 10A / 50V × 20A, 连续 2 小时 | 温度 <100°C, 功率波动 <3% |
| 满功率效率 | 测量输入总功率 vs 消耗功率 | 辅助电源功耗 <10W |
| 功率线性度 | 10%–100% 功率步进, 10% 间隔 | 线性度 R² >0.999 |
| 最大功率点 | 逐步提高功率直到保护触发 | ≥1050W 触发限值 |

#### 4.5.2 动态响应测试

| 测试项 | 条件 | 判定标准 |
|---|---|---|
| 大信号阶跃 | 10%–90% 负载阶跃 | 过冲 <10%, 稳定时间 <5ms |
| 动态负载 | 1k/5k/10kHz, 50% 占空比 | 跟踪误差 <5% |
| 保护响应时间 | OCP/OVP 触发 → MOSFET 关断 | <10μs (硬件) / <100μs (软件) |

#### 4.5.3 通信 & 人机交互

| 测试项 | 条件 | 判定标准 |
|---|---|---|
| OLED 显示刷新 | 实时显示 V/I/P/T | 刷新率 ≥5Hz |
| CAN 通信 | 100k/500k/1M bps | 24h 无丢帧 |
| USB 串口 | 115200 bps, 连续 1h | 无断连 |
| WiFi (ESP32) | 局域网 TCP 连接 | 延迟 <100ms |

#### 4.5.4 整机可靠性

| 测试项 | 条件 | 判定标准 |
|---|---|---|
| 高低温 (可选) | 40°C / 85°C 环境仓 (若有) | 功能正常, 精度满足 |
| 振动 (可选) | 运输振动模拟 | 无结构松动 |
| 42V 汽车级输入 (可选) | 输入 42V/1000W 持续 | 满足设计指标 |
| 全天候运行 | 48h 连续加载 | 零故障 |

### 4.6 关键风险 (Phase 3)

| 风险 | 概率 | 影响 | 缓解 |
|---|---|---|---|
| 12 管均流严重不均 | 中 | 局部 MOSFET 过载 | 每管独立检流, 固件动态调整 |
| 散热器热阻不足 | 低 | 超温保护 | 选型时留 20% 余量 |
| EMC 问题显著 | 中 | 传导/辐射发射超标 | 预留 EMI 滤波器和磁珠位置 |
| PCB 热应力失效 | 低 | PCB 变形/焊点开裂 | 选用 TG170 板材, 大铜面加散热过孔 |
| C2000 PWM 资源不足 | 低 | 需分时/复用 | 确认 F28E12x HRPWM 通道数 (≥12) |

---

## 5. 全阶段汇总

### 5.1 时间线

```
Week   7     8     9     10    11    12    13    14
       ┌─────┐ ┌─────────────┐ ┌──────────────────┐
Phase 1│Single Cell（100W）   │                     │
       └─────┘ └─────────────┘ └──────────────────┘
Phase 2              │  4 Cells（400W）  │
                     └──────────────────┘
Phase 3                                    │12Cells(1000W)│
                                           └──────────────┘
       ┌─────┬─────┬─────┬─────┬─────┬─────┬─────┬─────┐
Deliver │HRPWM│PID  │ 均流 │400W │CAN  │1000W│ 保护 │ 定型 │
able   │验证 │闭环 │ 验证 │满载 │通信 │满载 │ 验证 │ 确认 │
       └─────┴─────┴─────┴─────┴─────┴─────┴─────┴─────┘
```

### 5.2 预算总汇

| 阶段 | 投入 (¥) | 周期 |
|---|---|---|
| Phase 1 — 单管面包板 | ~350 | 2 周 |
| Phase 2 — 4 管打样 PCB | ~500 | 3 周 |
| Phase 3 — 12 管完整原型 | ~1,200 | 3 周 |
| **原型验证总投入** | **~¥2,050** | **8 周** |

### 5.3 所需仪器设备清单

| 设备 | 用途 | 已有/需购 | 参考型号 |
|---|---|---|---|
| 数字示波器 (4ch, ≥100MHz) | PWM/驱动/纹波测量 | 需备 | Rigol DS1104Z / Siglent SDS1104X-U |
| 直流电源 (0–100V, ≥10A) | 测试供电源 | 需备 | Korad KA3005P / Ruidian DPS5015 |
| 直流电子负载 (已有) | 校准/对比 | 已有 | 用作校准基准 |
| 数字万用表 (4.5 位+) | 电压/电流/电阻测量 | 需备 | Fluke 17B+ / Victor VC890C+ |
| 热像仪 (或 K 型热电偶) | 热分布测量 | 可选 | Seek Thermal / HTI HT-19 (¥500) |
| 可调电阻负载 | 大功率负载测试 | 需备 | 1kW 电阻箱 (或水阻) |
| 信号发生器 | 调试运放/滤波器 | 可选 | FeelTech FY6900 |
| USB-CAN 分析仪 | CAN 通信调试 | 需备 | USB-CAN / ZLG USBCAN-I |
| 逻辑分析仪 (可选) | SPI/I2C 调试 | 可选 | LA1010 / Saleae 克隆 |
| 示波器电流探头 (可选) | MOSFET 电流波形 | 可选 | 自制 Rogowski 线圈 |

---

## 6. 附录：快速参考

### 6.1 C2000 Pin 分配建议 (Phase 1)

| C2000 Pin | 功能 | 连接 |
|---|---|---|
| GPIO0 (HRPWM1A) | PWM 输出 | → 10Ω → 推挽输入 |
| ADCINA0 | 电流采样 | ← INA 输出 |
| ADCINA1 | 电压采样 | ← 分压电阻 |
| GPIO1 | 故障指示 (LED) | → LED+220Ω |
| GPIO2 | 使能开关 | → 按键/跳线 |
| GPIO3 (可选) | 触发输出 | → 示波器触发 |

### 6.2 PID 初始参数建议

| 参数 | 恒流 (CC) | 恒压 (CV) | 恒功率 (CP) |
|---|---|---|---|
| Kp | 0.1–0.5 | 0.5–2.0 | 0.2–1.0 |
| Ki | 10–50 | 50–200 | 20–100 |
| Kd | 0 (先不用) | 0 (先不用) | 0 (先不用) |
| PWM 频率 | 100kHz | 100kHz | 100kHz |
| 采样率 | 20–50kSPS | 20–50kSPS | 20–50kSPS |

> 建议先用 Ziegler-Nichols 整定法：增大 Kp 直到振荡，记录 Ku 和 Tu，再计算 PID 参数。

### 6.3 Phase 1 快速开始 Checklist

- [ ] 环境搭建: CCS / Code Composer Studio
- [ ] C2000ware 安装 / 例程导入
- [ ] HRPWM 例程烧录: 确认 PWM 输出
- [ ] ADC 例程烧录: 确认电压/电流读取
- [ ] 面包板搭建功率回路
- [ ] 开环验证: 固定占空比, 测量电流
- [ ] PID 循环写入
- [ ] 闭环调参: CC 模式
- [ ] CV / CP / CR 模式
- [ ] 动态负载测试
- [ ] Phase 1 评审 → 进入 Phase 2

---

**版本历史**

| 版本 | 日期 | 变更内容 | 编制人 |
|---|---|---|---|
| v0.1 | 2026-05-31 | 初稿 — 三阶段原型验证策略 | — |

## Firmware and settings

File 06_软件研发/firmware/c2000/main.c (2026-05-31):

/**
 * @file    main.c
 * @brief   EL-1000 C2000 F28E12x firmware entry point.
 *          Initializes hardware, creates tasks, starts FreeRTOS scheduler.
 */

#include "FreeRTOSConfig.h"
#include "gpio.h"
#include "adc.h"
#include "hrpwm.h"
#include "uart.h"
#include "cmpss.h"
#include "timer.h"
#include "pid.h"
#include "modes.h"
#include "el1000_types.h"
#include "protocol.h"

/* ─── Task handles ─────────────────────────────────────────────────── */
TaskHandle_t g_pid_task_handle;
TaskHandle_t g_protection_task_handle;
TaskHandle_t g_comm_task_handle;
TaskHandle_t g_housekeeping_task_handle;

/* ─── Queues ───────────────────────────────────────────────────────── */
QueueHandle_t g_telemetry_queue;    /**< Telemetry data to ESP32 */
QueueHandle_t g_command_queue;      /**< Incoming commands from ESP32 */
QueueHandle_t g_log_queue;          /**< Log/event messages */

/* ─── Global state ─────────────────────────────────────────────────── */
el1000_setpoints_t g_setpoints;     /**< Current operating setpoints */
el1000_telemetry_t  g_telemetry;    /**< Latest telemetry sample */
el1000_sys_status_t g_sys_status;   /**< System status & flags */
el1000_calibration_t g_cal;         /**< Calibration data */

/* ─── External task functions ──────────────────────────────────────── */
extern void pid_task(void *pvParameters);
extern void protection_task(void *pvParameters);
extern void comm_task(void *pvParameters);
extern void housekeeping_task(void *pvParameters);

/**
 * @brief  Board-level initialization.
 *         Called before the scheduler starts. Configures clocks,
 *         GPIO, peripherals, and sets default operating state.
 *
 * TODO: Implement device-specific register configuration:
 *       - DeviceInit() / SysCtrl for 120 MHz SYSCLK
 *       - Disable watchdog
 *       - Configure PLL, clock dividers
 *       - Enable FPU32
 */
static void board_init(void)
{
    /* ─── Watchdog & Clock ─────────────────────────────────────────── */
    /* TODO: Disable watchdog timer (WdRegs) */
    /* TODO: InitPll(DSP28_PLLCR, DSP28_DIVSEL) for 120 MHz SYSCLK */
    /* TODO: Enable peripheral clocks (SCI-A, ADC-A/B, ePWM1-4, CMPSS) */

    /* ─── GPIO ─────────────────────────────────────────────────────── */
    gpio_init();

    /* ─── Peripherals ──────────────────────────────────────────────── */
    adc_init();       /* 13-channel sequential sampling */
    hrpwm_init();     /* 25 kHz, HRPWM enabled on ePWM1-2 */
    cmpss_init();     /* CMPSS1 (OVP), CMPSS2 (OCP) */
    uart_init();      /* SCI-A @ 921600 baud */

    /* ─── Control variables ────────────────────────────────────────── */
    pid_init(&g_pid_state);
    modes_init(&g_setpoints);

    /* Default to idle, no protection flags */
    g_sys_status.status          = STATUS_IDLE;
    g_sys_status.protection_flags = PROT_NONE;
    g_sys_status.uptime_sec      = 0;
}

/**
 * @brief  FreeRTOS tick hook — called every tick interrupt.
 *         Used for uptime tracking and watchdog servicing.
 *
 * TODO: Kick hardware watchdog if used.
 */
void vApplicationTickHook(void)
{
    static uint32_t tick_count = 0;
    tick_count++;

    /* Increment uptime every 1000 ticks (1 second at 1 kHz tick) */
    if ((tick_count % 1000) == 0) {
        g_sys_status.uptime_sec++;
    }
}

/**
 * @brief  Malloc failed hook — called if heap allocation fails.
 */
void vApplicationMallocFailedHook(void)
{
    taskDISABLE_INTERRUPTS();
    /* TODO: Set error LED pattern, halt */
    for (;;);
}

/**
 * @brief  Stack overflow hook — called when a task overflows.
 */
void vApplicationStackOverflowHook(TaskHandle_t xTask, char *pcTaskName)
{
    (void)xTask;
    (void)pcTaskName;
    taskDISABLE_INTERRUPTS();
    /* TODO: Set error LED pattern, log fault */
    for (;;);
}

/**
 * @brief  Main entry point.
 *         Initializes the board, creates FreeRTOS tasks,
 *         then starts the scheduler (never returns).
 */
int main(void)
{
    /* Disable interrupts during init */
    __asm("        setc    INTM");

    board_init();

    /* Create queues */
    g_telemetry_queue = xQueueCreate(QUEUE_LENGTH_TELEMETRY, sizeof(el1000_telemetry_t));
    g_command_queue   = xQueueCreate(QUEUE_LENGTH_COMMANDS,  sizeof(proto_frame_t));
    g_log_queue       = xQueueCreate(QUEUE_LENGTH_LOG,       sizeof(char[64]));

    if (!g_telemetry_queue || !g_command_queue || !g_log_queue) {
        /* TODO: Handle queue creation failure — flash error LED */
        for (;;);
    }

    /* Create tasks */
    xTaskCreate(pid_task,           "PID",          512, NULL, PID_TASK_PRIORITY,          &g_pid_task_handle);
    xTaskCreate(protection_task,    "PROT",         256, NULL, PROTECTION_TASK_PRIORITY,   &g_protection_task_handle);
    xTaskCreate(comm_task,          "COMM",         512, NULL, COMM_TASK_PRIORITY,          &g_comm_task_handle);
    xTaskCreate(housekeeping_task, "HOUSEKEEP",    256, NULL, HOUSEKEEPING_TASK_PRIORITY,  &g_housekeeping_task_handle);

    /* Re-enable interrupts and start scheduler */
    __asm("        clrc    INTM");
    vTaskStartScheduler();

    /* Should never reach here */
    for (;;);
    return 0;
}

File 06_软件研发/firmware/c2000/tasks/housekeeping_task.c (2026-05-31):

/**
 * @file    housekeeping_task.c
 * @brief   Low-priority housekeeping task.
 *
 * Runs at ~10 Hz. Responsibilities:
 *   - ADC oversampling / averaging for slow channels (temperature, PSU)
 *   - System status LED patterns
 *   - Debug log messages via the log queue
 *   - Fan speed control based on temperature
 *   - Periodic EEPROM/FRAM save for settings persistence
 *   - Supervisor — check if PID task is still running (watchdog)
 */

#include "FreeRTOSConfig.h"
#include "adc.h"
#include "gpio.h"
#include "modes.h"
#include "el1000_types.h"
#include <string.h>

/* ─── LED blink patterns ───────────────────────────────────────────── */
#define LED_BLINK_NORMAL    250    /* 250 ms on/off */
#define LED_BLINK_FAULT     100    /* 100 ms fast blink */
#define LED_BLINK_COMMS     500    /* 500 ms slow blink */
#define LED_BLINK_IDLE      1000   /* 1 s single pulse */

/* ─── Oversampling ─────────────────────────────────────────────────── */
#define OVERSAMPLE_COUNT    20     /* Average 20 readings at 860 Hz ~23 ms */

static struct {
    float temp_sum;
    float psu_sum;
    uint32_t sample_count;
} g_oversample;

/* ─── Task runtime stats ───────────────────────────────────────────── */
static uint32_t g_task_iterations = 0;
static uint32_t g_pid_task_watchdog = 0;

/* Forward declaration of PID task iteration counter from pid_task.c */
/* In production, the PID task would increment a shared counter */

/**
 * @brief  Housekeeping task.
 *
 * @param  pvParameters  Unused.
 */
void housekeeping_task(void *pvParameters)
{
    (void)pvParameters;
    TickType_t last_wake = xTaskGetTickCount();

    /* Initialize oversample buffer */
    memset(&g_oversample, 0, sizeof(g_oversample));

    for (;;) {
        vTaskDelayUntil(&last_wake, pdMS_TO_TICKS(100));  /* 10 Hz */

        g_task_iterations++;

        /* ─── 1. Oversample slow ADC channels ─────────────────────────── */
        g_oversample.temp_sum += adc_read_temperature(ADC_CH_TEMP1);
        g_oversample.psu_sum  += (float)adc_read_psu_mv();
        g_oversample.sample_count++;

        if (g_oversample.sample_count >= OVERSAMPLE_COUNT) {
            float avg_temp = g_oversample.temp_sum / (float)OVERSAMPLE_COUNT;
            float avg_psu  = g_oversample.psu_sum / (float)OVERSAMPLE_COUNT;

            /* Update global status with averaged values */
            /* TODO: Store averaged temperature, PSU voltage */
            /* g_sys_status.psu_voltage_mv = (uint16_t)avg_psu; */

            /* Fan speed control based on temperature */
            /* TODO: Implement fan speed curve
             *   if (avg_temp < 40.0f)   fan_duty = 0.3f;   // 30%
             *   if (avg_temp > 70.0f)   fan_duty = 1.0f;   // 100%
             *   hrpwm_set_duty_epwm2((uint16_t)(fan_duty * 2400));
             */

            /* Reset */
            g_oversample.temp_sum = 0.0f;
            g_oversample.psu_sum  = 0.0f;
            g_oversample.sample_count = 0;
        }

        /* ─── 2. Status LED patterns ──────────────────────────────────── */
        if (g_sys_status.protection_flags != PROT_NONE) {
            /* Fault: fast red blink */
            gpio_toggle(GPIO_LED_FAULT);
            gpio_clear(GPIO_LED_STATUS);
        } else if (g_sys_status.status == STATUS_RUNNING) {
            /* Running: solid green */
            gpio_set(GPIO_LED_STATUS);
            gpio_clear(GPIO_LED_FAULT);
        } else if (g_sys_status.protection_flags & PROT_COMMS_LOST) {
            /* Comms lost: slow blue blink */
            gpio_toggle(GPIO_LED_WIFI);
            gpio_clear(GPIO_LED_STATUS);
        } else {
            /* Idle: slow green pulse */
            gpio_toggle(GPIO_LED_STATUS);
            gpio_clear(GPIO_LED_FAULT);
        }

        /* ─── 3. PID task watchdog ─────────────────────────────────────── */
        /* Check that g_pid_state.run_count has increased since last check.
         * If not, the PID task may be stuck.
         */
        /* TODO: Compare current run_count with stored value
         *   uint32_t current_run = g_pid_state.run_count;
         *   if (current_run == g_pid_task_watchdog) {
         *       // PID task not running — emergency shutdown
         *       hrpwm_force_shutdown();
         *       modes_set_output(&g_modes, false);
         *       g_sys_status.status = STATUS_FAULT;
         *       g_sys_status.protection_flags |= PROT_FAULT;
         *   }
         *   g_pid_task_watchdog = current_run;
         */

        /* ─── 4. Push telemetry to queue for comm_task ───────────────── */
        /* xQueueOverwrite(g_telemetry_queue, &g_telemetry); */

        /* ─── 5. Debug log (optional) ──────────────────────────────────── */
        /* char log_buf[64];
         * snprintf(log_buf, sizeof(log_buf), "V=%.2f I=%.2f T=%d",
         *          g_telemetry.voltage, g_telemetry.current,
         *          g_telemetry.temperature_c);
         * xQueueSend(g_log_queue, log_buf, 0);
         */
    }
}
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

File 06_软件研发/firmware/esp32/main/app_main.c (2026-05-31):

/**
 * @file    app_main.c
 * @brief   ESP32-S3 entry point for EL-1000.
 *
 * Initializes:
 *   - NVS flash storage
 *   - Wi-Fi (STA + AP modes)
 *   - UART communication with C2000
 *   - WebSocket and REST API servers
 *   - LVGL display driver
 *   - Rotary encoder and keypad
 *   - Data logging ring buffer
 *
 * Then starts FreeRTOS tasks for each subsystem.
 */

#include <stdio.h>
#include <string.h>
#include "freertos/FreeRTOS.h"
#include "freertos/task.h"
#include "esp_system.h"
#include "esp_log.h"
#include "nvs_flash.h"

#include "uart_comms.h"
#include "webserver.h"
#include "websocket.h"
#include "display.h"
#include "encoder.h"
#include "keypad.h"
#include "wifi.h"
#include "data_log.h"

static const char *TAG = "EL1000_MAIN";

void app_main(void)
{
    ESP_LOGI(TAG, "EL-1000 ESP32-S3 firmware starting...");

    /* ─── Initialize NVS ───────────────────────────────────────────── */
    esp_err_t ret = nvs_flash_init();
    if (ret == ESP_ERR_NVS_NO_FREE_PAGES || ret == ESP_ERR_NVS_NEW_VERSION_FOUND) {
        ESP_ERROR_CHECK(nvs_flash_erase());
        ret = nvs_flash_init();
    }
    ESP_ERROR_CHECK(ret);

    /* ─── Initialize subsystems ────────────────────────────────────── */
    wifi_init();            /* Wi-Fi manager */
    uart_comms_init();      /* UART to C2000 */
    webserver_init();       /* REST API */
    websocket_init();       /* WebSocket real-time data */
    display_init();         /* LVGL + 4.3" IPS LCD */
    encoder_init();         /* Rotary encoder */
    keypad_init();          /* Button matrix */
    data_log_init();        /* Ring buffer logging */

    ESP_LOGI(TAG, "All subsystems initialized. System ready.");
    ESP_LOGI(TAG, "Connect via Web UI at http://el1000.local/");
}

/**
 * TODO:
 *   - Implement OTA firmware update via WebSocket
 *   - Add mDNS responder for "el1000.local" discovery
 *   - Add MQTT bridge for home automation integration
 *   - Implement SCPI command parser for lab equipment interoperability
 */

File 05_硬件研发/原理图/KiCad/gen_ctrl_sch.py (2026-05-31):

#!/usr/bin/env python3
"""
Generate EL-1000 Control Circuit schematic (.kicad_sch)
Based on SYS-SCH-002 v0.1 design document

Contains:
  - C2000 F28E12x minimum system (48-pin LQFP)
  - ESP32-S3-WROOM-1 module
  - SGM71622R2 DAC (SPI)
  - ADS1115 ADC (I2C)
  - ISO7741 digital isolator
  - ADuM1201 UART isolator
  - ADuM3160 USB isolator
  - LCD 4.3" IPS connector
  - Encoder + keypad
  - JTAG + power rails
"""

import uuid, os

OUTDIR = os.path.dirname(os.path.abspath(__file__))

def uid():
    return str(uuid.uuid4()).upper()

# ============================================================
# HEADER
# ============================================================
HEADER = f"""(kicad_sch (version 20230121) (generator eeschema)

  (uuid {uid()})

  (paper "A3" portrait)

  (title_block
    (title "EL-1000 Control Circuit v0.1")
    (date "2026-05-31")
    (rev "0.1")
    (comment 1 "C2000 F28E12x + ESP32-S3 dual MCU")
    (comment 2 "ADC:ADS1115 | DAC:SGM71622R2 | ISO:ISO7741+ADuM1201+ADuM3160")
    (comment 4 "BOM ~196 | SPI+I2C+UART+JTAG")
  )

  (lib_symbols
    (symbol "power:GND" (power) (pin_names (offset 0)) (in_bom yes) (on_board yes)
      (property "Reference" "#PWR" (at 0 -6.35 0) (effects (font (size 1.27 1.27)) hide))
      (property "Value" "GND" (at 0 -3.81 0) (effects (font (size 1.27 1.27))))
      (property "Footprint" "" (at 0 0 0) (effects (font (size 1.27 1.27)) hide))
      (property "Datasheet" "" (at 0 0 0) (effects (font (size 1.27 1.27)) hide))
      (symbol "power:GND_0_1"
        (polyline (pts (xy 0 0) (xy 0 -1.27) (xy 1.27 -1.27) (xy 0 -2.54) (xy -1.27 -1.27) (xy 0 -1.27)) (stroke (width 0) (type default)) (fill (type none))))
      (symbol "power:GND_1_1"
        (pin power_in line (at 0 0 270) (length 0) hide (name "GND" (effects (font (size 1.27 1.27)))) (number "1" (effects (font (size 1.27 1.27)))))))
    (symbol "power:+3V3" (power) (pin_names (offset 0)) (in_bom yes) (on_board yes)
      (property "Reference" "#PWR" (at 0 -3.81 0) (effects (font (size 1.27 1.27)) hide))
      (property "Value" "+3.3V" (at 0 3.556 0) (effects (font (size 1.27 1.27))))
      (property "Footprint" "" (at 0 0 0) (effects (font (size 1.27 1.27)) hide))
      (property "Datasheet" "" (at 0 0 0) (effects (font (size 1.27 1.27)) hide))
      (symbol "power:+3V3_0_1"
        (polyline (pts (xy -0.762 1.27) (xy 0 2.54)) (stroke (width 0) (type default)) (fill (type none)))
        (polyline (pts (xy 0 0) (xy 0 2.54)) (stroke (width 0) (type default)) (fill (type none)))
        (polyline (pts (xy 0 2.54) (xy 0.762 1.27)) (stroke (width 0) (type default)) (fill (type none))))
      (symbol "power:+3V3_1_1"
        (pin power_in line (at 0 0 90) (length 0) hide (name "+3.3V" (effects (font (size 1.27 1.27)))) (number "1" (effects (font (size 1.27 1.27)))))))
    (symbol "power:+5V" (power) (pin_names (offset 0)) (in_bom yes) (on_board yes)
      (property "Reference" "#PWR" (at 0 -3.81 0) (effects (font (size 1.27 1.27)) hide))
      (property "Value" "+5V" (at 0 3.556 0) (effects (font (size 1.27 1.27))))
      (property "Footprint" "" (at 0 0 0) (effects (font (size 1.27 1.27)) hide))
      (property "Datasheet" "" (at 0 0 0) (effects (font (size 1.27 1.27)) hide))
      (symbol "power:+5V_0_1"
        (polyline (pts (xy -0.762 1.27) (xy 0 2.54)) (stroke (width 0) (type default)) (fill (type none)))
        (polyline (pts (xy 0 0) (xy 0 2.54)) (stroke (width 0) (type default)) (fill (type none)))
        (polyline (pts (xy 0 2.54) (xy 0.762 1.27)) (stroke (width 0) (type default)) (fill (type none))))
      (symbol "power:+5V_1_1"
        (pin power_in line (at 0 0 90) (length 0) hide (name "+5V" (effects (font (size 1.27 1.27)))) (number "1" (effects (font (size 1.27 1.27)))))))
    (symbol "power:+12V" (power) (pin_names (offset 0)) (in_bom yes) (on_board yes)
      (property "Reference" "#PWR" (at 0 -3.81 0) (effects (font (size 1.27 1.27)) hide))
      (property "Value" "+12V" (at 0 3.556 0) (effects (font (size 1.27 1.27))))
      (property "Footprint" "" (at 0 0 0) (effects (font (size 1.27 1.27)) hide))
      (property "Datasheet" "" (at 0 0 0) (effects (font (size 1.27 1.27)) hide))
      (symbol "power:+12V_0_1"
        (polyline (pts (xy -0.762 1.27) (xy 0 2.54)) (stroke (width 0) (type default)) (fill (type none)))
        (polyline (pts (xy 0 0) (xy 0 2.54)) (stroke (width 0) (type default)) (fill (type none)))
        (polyline (pts (xy 0 2.54) (xy 0.762 1.27)) (stroke (width 0) (type default)) (fill (type none))))
      (symbol "power:+12V_1_1"
        (pin power_in line (at 0 0 90) (length 0) hide (name "+12V" (effects (font (size 1.27 1.27)))) (number "1" (effects (font (size 1.27 1.27)))))))
    (symbol "power:+1V2" (power) (pin_names (offset 0)) (in_bom yes) (on_board yes)
      (property "Reference" "#PWR" (at 0 -3.81 0) (effects (font (size 1.27 1.27)) hide))
      (property "Value" "+1.2V" (at 0 3.556 0) (effects (font (size 1.27 1.27))))
      (property "Footprint" "" (at 0 0 0) (effects (font (size 1.27 1.27)) hide))
      (property "Datasheet" "" (at 0 0 0) (effects (font (size 1.27 1.27)) hide))
      (symbol "power:+1V2_0_1"
        (polyline (pts (xy -0.762 1.27) (xy 0 2.54)) (stroke (width 0) (type default)) (fill (type none)))
        (polyline (pts (xy 0 0) (xy 0 2.54)) (stroke (width 0) (type default)) (fill (type none)))
        (polyline (pts (xy 0 2.54) (xy 0.762 1.27)) (stroke (width 0) (type default)) (fill (type none))))
      (symbol "power:+1V2_1_1"
        (pin power_in line (at 0 0 90) (length 0) hide (name "+1.2V" (effects (font (size 1.27 1.27)))) (number "1" (effects (font (size 1.27 1.27)))))))
    (symbol "Device:R" (pin_numbers hide) (pin_names (offset 0)) (in_bom yes) (on_board yes)
      (property "Reference" "R" (at 2.032 0 90) (effects (font (size 1.27 1.27))))
      (property "Value" "R" (at 0 0 90) (effects (font (size 1.27 1.27))))
      (property "Footprint" "" (at -1.778 0 90) (effects (font (size 1.27 1.27)) hide))
      (property "Datasheet" "~" (at 0 0 0) (effects (font (size 1.27 1.27)) hide))
      (symbol "Device:R_0_1" (rectangle (start -1.016 -2.54) (end 1.016 2.54) (stroke (width 0.254) (type default)) (fill (type none))))
      (symbol "Device:R_1_1"
        (pin passive line (at 0 3.81 270) (length 1.27) (name "~" (effects (font (size 1.27 1.27)))) (number "1" (effects (font (size 1.27 1.27)))))
        (pin passive line (at 0 -3.81 90) (length 1.27) (name "~" (effects (font (size 1.27 1.27)))) (number "2" (effects (font (size 1.27 1.27)))))))
    (symbol "Device:C" (pin_numbers hide) (pin_names (offset 0.254)) (in_bom yes) (on_board yes)
      (property "Reference" "C" (at 0.635 2.54 0) (effects (font (size 1.27 1.27)) (justify left)))
      (property "Value" "C" (at 0.635 -2.54 0) (effects (font (size 1.27 1.27)) (justify left)))
      (property "Footprint" "" (at 0.9652 -3.81 0) (effects (font (size 1.27 1.27)) hide))
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

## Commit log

2026-05-26 Init: 1000W DC Electronic Load project scaffolding
    - 12-dimension closed-loop management framework v3.0
    - Market analysis PPT (CN/EN)
    - Project master plan with 24-week schedule
    - W1 deliverables: competitor purchase guide + user interview guide
    - Folder structure with per-dimension README
2026-05-26 SRD v1.0: 1200W product specification locked
    - Power: 1200W continuous / 1500W peak
    - Dynamic: 25kHz (matching ITECH IT8512+)
    - Topology: pure linear MOSFET bank with Buck pre-regulation as fallback
    - Added SRD to 02_产品定义/
    - Added meeting record MTG-001 to _meeting_notes/
    Key decisions:
    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
2026-05-26 Docs: complete session log archive
    - Added 项目全讨论记录_20260526.docx with all 7 sessions logged
    - Covers timeline from 500W→1000W→1200W, 10→12 dimensions
    - 10 key decisions documented with rationale and linked outputs
    - File inventory by dimension (completed + pending)
2026-05-26 SRD v1.1: thermal analysis correction
    - MOSFET count corrected from 8 to 12-20 based on thermal math
    - Added thermal calculation section with junction temp analysis
    - Added temperature derating curve (6-level)
    - Added BOM impact assessment (+¥190 for 20-FET config)
    - Added meeting record MTG-002
    Key finding: 8-FET at 150W each → Tj=234°C (impossible)
    20-FET at 60W each → Tj=124°C (safe)
2026-05-26 SRD v1.2: thermal optimization + MOSFET alternatives
    - MOSFET count reduced from 20 to 10-12 via package/insulator optimization
    - TO-247 (RthJC 0.45) + AlN ceramic pad (RthCS 0.15) → thermal chain halved
    - Added MOSFET alternative sourcing table (8 options including domestic)
    - SiC analysis: unsuitable for linear mode
    - Added component test plan with ¥215 budget
    - Meeting record MTG-003
2026-05-26 Add MTG-000: management framework & team design (backfill)
    Covers two early sessions before MTG numbering was established:
    - Session A: 10→11→12 dimension framework evolution (v1→v3)
    - Session B: 12 dimensions → 4 roles merge strategy
    - Session C: AI capability boundary & human-AI collaboration model
2026-05-26 System design: safety architecture framework v0.1 (discussion draft)
    6-layer defense-in-depth:
    1. Physical safety (enclosure, grounding, IP20)
    2. Electrical isolation (2500Vrms, control↔power domain)
    3. Sensor monitoring (3-pt temp, V/I, fan RPM)
    4. Logic judgment (FW + HW comparators, independent)
    5. Actuator cutoff (gate pull-down + relay disconnect)
    6. Watchdog & recovery (independent IC, fail-safe)
    Includes FMEA for 8 critical failure modes + 7 decisions pending discussion
2026-05-26 Safety architecture v1.1: 4 decisions confirmed
    Decisions:
    - D1: Relay kept (independent physical disconnect)
    - D2: 125A fast-blow fuse added (ultimate last resort)
    - D3: Dual fan + RPM detection + 12V monitoring (no 3rd fan)
    - D4: 4× NTC + dT/dt predictive thermal monitoring
    Three-cutoff defense:
    1. MOSFET gate pull-down (≤15μs) - primary
    2. Relay disconnect (5-10ms) - independent backup
    3. Input fuse (ultimate, non-resettable)
    Total safety BOM increase: ¥32.5
2026-05-26 Safety architecture finalized: 8 decisions confirmed
    All 8 safety architecture decisions resolved:
    - D1: Relay kept (independent physical cutoff)
    - D2: 125A fast-blow fuse added
    - D3: Dual fan + RPM monitoring + 12V supervision
    - D4: 4x NTC + dT/dt predictive thermal monitoring
    - D5: ±500V isolation to ground (matches ITECH/Chroma)
    - D6: 1.6s watchdog (TPS3823)
    - D7: Mixed recovery strategy (manual default + remote reset)
    - D8: Configurable protection thresholds (±15%, never disable)
    Safety BOM: ¥77.5 total (¥32.5 incremental)
    Meetings: MTG-004
2026-05-26 Power tree architecture finalized: all-digital PSU design
    8 decisions confirmed:
    - P1: Built-in flyback on separate PCB (70x50mm)
    - P2: TMS320F28E12x (48-pin, C28x DSP@160MHz)
    - P3: C2000 directly drives flyback via ISO7721+UCC27524
    - P4: C2000 PWM drives all 3 Bucks + charge pump
    - P5: 7/8 MCPWM channels used, 1 spare
    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
2026-05-26 Power topology T2 confirmed: dual shunt + ADS1115 current sensing
    T2 decision:
    - 12 MOSFETs split into 2 groups (6+6)
    - Dual manganin shunt 0.002Ω/3W per group
    - ADS1115: Ch1=GroupA (30A), Ch2=GroupB (30A), total=I(A)+I(B)
    - INA180×2 for shunt signal conditioning
    - LM358 summing → CMPSS1 for hardware OCP (<100ns)
    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
2026-05-26 Power topology T1-T3 confirmed: 2-group drive + dual shunt + DAC direct
    T1: 2-group gate drive (DAC80508 ChA/B -> OPA548-A/B -> 6+6 MOSFETs)
    T2: Dual manganin shunt 0.002R + ADS1115 2-ch diff + LM358 sum -> CMPSS1 OCP
    T3: DAC direct drive for 25kHz dynamic, ~8us delay < 15us SRD requirement
    Drive BOM: ~¥101
    Documents: SYS-ARCH-003 v0.2 + MTG-006 complete
2026-05-26 Power topology finalized: M90N20 x8 confirmed
    T5 MOSFET selection via datasheet analysis:
    - M90N20: PD=580W, SOA@100V=4.0A, RthJC=0.22C/W
    - Only 6-8 devices needed vs 12 for IRFP460
    - 8-FET config: Tj=107C, 43C margin
    Documents: SYS-ARCH-003 v1.0 final + MTG-007
2026-05-26 Power topology 7/7 complete: T6-T7 confirmed
    T6: Buck pre-regulation pads reserved on PCB (V1.0 bypass, V2.0 optional)
    T7: Reverse polarity protection via MBR20100CT + voltage polarity detect
    Power stage BOM: ~¥128
    Documents: SYS-ARCH-003 complete + MTG-008
2026-05-26 Control architecture C1-C4 confirmed: 860Hz PID + hybrid sampling
    C1: 860Hz single precision PID (ADS1115), sufficient for steady-state
    C2: Dual-rate hybrid (ADS1115 precision PID + internal ADC+CMPSS protection)
    C3: Outer loop 1kHz (CV/CP/CR -> I_set to inner loop)
    C4: Incremental PID + anti-windup clamping
2026-05-26 Communication protocol complete: M1-M6 all confirmed
    ESP32-S3-WROOM-1 module + ADuM1201 isolator, comm BOM ~¥25
    System design: 5/6 modules done, only ID/Structure remaining
2026-05-26 M7-M8: PMBus + CANbus added to communication ports
    M7: PMBus (I2C software stack, F28E12x I2C, ¥0.5)
    M8: CANbus (ESP32 TWAI + SN65HVD230, ¥7)
    Full port list: Wi-Fi6 / BLE5 / USB-C / PMBus / CANbus / USB-A
    System design: 5/6 complete, 37 decisions confirmed
2026-05-26 ID/MD framework v0.1 created, paused for the day
    6/6 system design modules started, 5/6 completed
    Awaiting: S1-S7 ID/structural decisions tomorrow
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2026-05-29 Phase 03+04+12: 系统框图/热设计/SDR评审包 + SRD v1.3架构对齐 + 跨文档审查修复
    新增:
    - 系统框图 SVG (SYS-ARCH-000 v1.0)
    - 热设计报告+性能曲线 (SYS-ARCH-007-H v1.0)
    - SDR评审材料包 (SDR-001 v1.0)
    - SRD v1.3 — 架构对齐(C2000/M90N20/AC反激/EL-1000)
    修复:
    - 审查发现11项不一致, 修复5项严重问题
    - MOSFET管数统一为12管
    - SVG栅极驱动/反激控制/θSA/BOM修正
    - 删除意外提交的Office临时文件
    会议记录: MTG-014
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2026-05-30 W7: KiCad原理图首版 + 桌面自动化skill
    - 功率级原理图.kicad_sch (34KB, 1102行, kicad-cli验证通过)
    - HRPWM RC滤波 + 1/13.2分压 + RS6332运放
    - D882/B772推挽 | 12×M90N20阵列
    - 12×MCSF2512DR050Q9源极电阻
    - desktop-automation skill + x11_control.py
    - 功率级BOM: ~¥213
    [EL-1000_PowerStage.kicad_sch]
2026-05-30 功率级原理图: 加连线和网络标号
    - 53个元件 + 30条连线 + 5个net label + 5个章节标注
    - HRPWM RC滤波→分压→MOSFET栅极总线
    - Group A(130) / Group B(88) 栅极驱动总线
    - LOAD+ 漏极公共节点
    - kicad-cli验证通过
    [EL-1000_PowerStage.kicad_sch]
2026-05-30 功率级原理图完成: 精确引脚连接+反馈回路
    - 51个元件精确放置, 56条走线按实际引脚连接
    - 信号流: HRPWM→RC滤波→分压→RS6332→推挽→MOSFET栅极
    - RS6332闭环: V_REF→IN+, SUM_NODE→IN-, OUT→推挽
    - VCC→+5V, VEE→GND
    - 12× M90N20两组, 每管独立源极电阻
    - 6个net label + 7个章节标注
    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
    [EL-1000_PowerStage.kicad_sch]
2026-05-31 W7: 系统问题修复完成 — 控制电路/电源树原理图 + 固件骨架 + 算法仿真 + 认证/BOM/供应链文档
    基于Codex评估修复10项问题：
    🔴 控制电路/电源树KiCad原理图落地（新增2张.sch）
    🔴 固件骨架建成（39文件：C2000+ESP32双MCU）
    🔴 控制算法设计文档+PID仿真（含5张分析图）
    🟠 安规认证策略（CE/FCC/UL两阶段方案）
    🟠 整机BOM核算（¥876→¥1,354含外壳/接插件/PCB/组装）
    🟠 供应链摸底框架（C2000🟠高风险8-12周）
    🟡 快速原型验证策略（3阶段¥2,050预算）
    🟡 .gitignore优化（~$过滤+LFS建议）
    📋 ISSUES-001问题跟踪清单发布
    📋 MTG-016会议纪要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
    [EL-1000_ControlCircuit.kicad_sch, EL-1000_PowerTree.kicad_sch]
2026-05-31 fix: pid.c max_integral 0.5→0.95 (pid_sim.py发现30A稳态duty需~0.88)
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2026-06-01 fix: PPT布局修正-无重叠/无占位字符, 20页图文版
